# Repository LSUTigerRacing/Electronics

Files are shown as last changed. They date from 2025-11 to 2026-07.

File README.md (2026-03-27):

<div align="center">
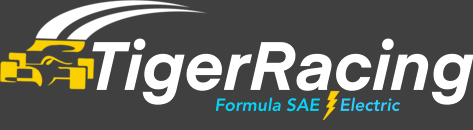
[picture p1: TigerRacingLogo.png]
TigerRacing Logo
    
</div>
<hr />
<div align="center">
    
</div>
<br />
<div align="center">
    This repository contains all of the KiCad Schematics for the TigerRacing Formula SAE's Electronics Subsystem.
</div>
<br />

## Prerequisites
* [Git](https://git-scm.com/downloads)
* [KiCad](https://www.kicad.org/download/)
* A [GitHub](https://github.com) account

## Board Templates
When making a new PCB, if the board is to be manufactured by **JLCPCB**. import the corresponding board constraints from `Board Templates/JLC` 

## Getting Started
This section will walk you through downloading the repository to your computer for the first time. You only need to do this once.

### 1. Generate a GitHub Token
A token is essentially a password that lets Git on your computer talk to GitHub securely.

1. Log into [GitHub](https://github.com)
2. Click your profile picture → **Settings**
3. Scroll down and click **Developer settings** (bottom of the left sidebar)
4. Click **Personal access tokens** → **Tokens (classic)**
5. Click **Generate new token (classic)**
6. Give it a name (e.g. `git-access`), set an expiration, and check the **repo** scope
7. Click **Generate token** and **copy it** — you won't be able to see it again!

### 2. Clone the Repository
"Cloning" means downloading a full copy of the repository to your computer.

Open **Git Bash** and run the following commands one at a time:
```sh
git clone https://github.com/LSUTigerRacing/Electronics.git
cd Electronics
```

When prompted for a password, paste the token you copied in the previous step.

### 3. Open the Project in KiCad
In **Git Bash**, highlight and right-click `Electronics` to open the folder in File Explorer. From there, open the KiCad project file (`.kicad_pro`).

---

## Contributing
This section covers the full workflow for making changes and submitting them every time you work on something.

> [!IMPORTANT]
> **Never commit directly to `main`.** All changes must go through a pull request.

### Step 1 — Make sure you're up to date
Before starting any work, pull the latest changes from the repository so you're not working on an outdated copy.
```sh
cd Electronics
git pull origin main
```

### Step 2 — Create a branch
A "branch" is your own isolated workspace. Think of it like making a photocopy of the project — you make your edits on the copy, and only merge it back once everything looks good.

Replace `your-branch-name` with something descriptive (e.g. `fault-latch-rework`).
```sh
git checkout -b "your-branch-name"
```

### Step 3 — Make your edits
Open the KiCad project and make your changes. Save your work when done.

### Step 4 — Stage and commit your changes
"Staging" tells Git which files to include, and "committing" saves a snapshot of those changes with a description.
```sh
git add .
git commit -m "Brief description of what you changed"
```

### Step 5 — Push your branch to GitHub
"Pushing" uploads your local branch so others (and GitHub) can see it.
```sh
git push -u origin "your-branch-name"
```

### Step 6 — Open a Pull Request
1. Go to the [repository on GitHub](https://github.com/LSUTigerRacing/Electronics)
2. Click the **Pull requests** tab
3. Click **New pull request**
4. Set the **base** branch to `main` and the **compare** branch to yours
5. Give it a clear title and description of what you changed
6. Click **Create pull request**

A reviewer will look over your changes. Once approved, your branch will be merged into `main` and can then be deleted.

---

## PCB Gallery

### Fault Latch
FaultLatch

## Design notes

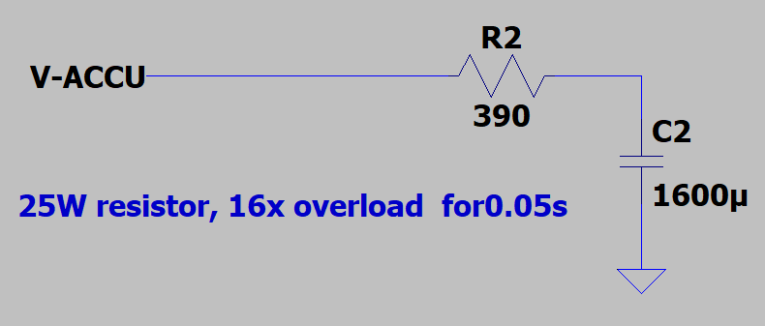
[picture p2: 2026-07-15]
PrechargeDischarge/Precharge26/docs/precharge-400V-390ohm-schematic.png

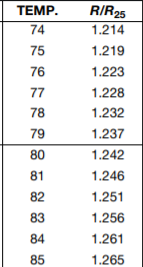
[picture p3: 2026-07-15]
PrechargeDischarge/Precharge26/docs/thermistor-response.png

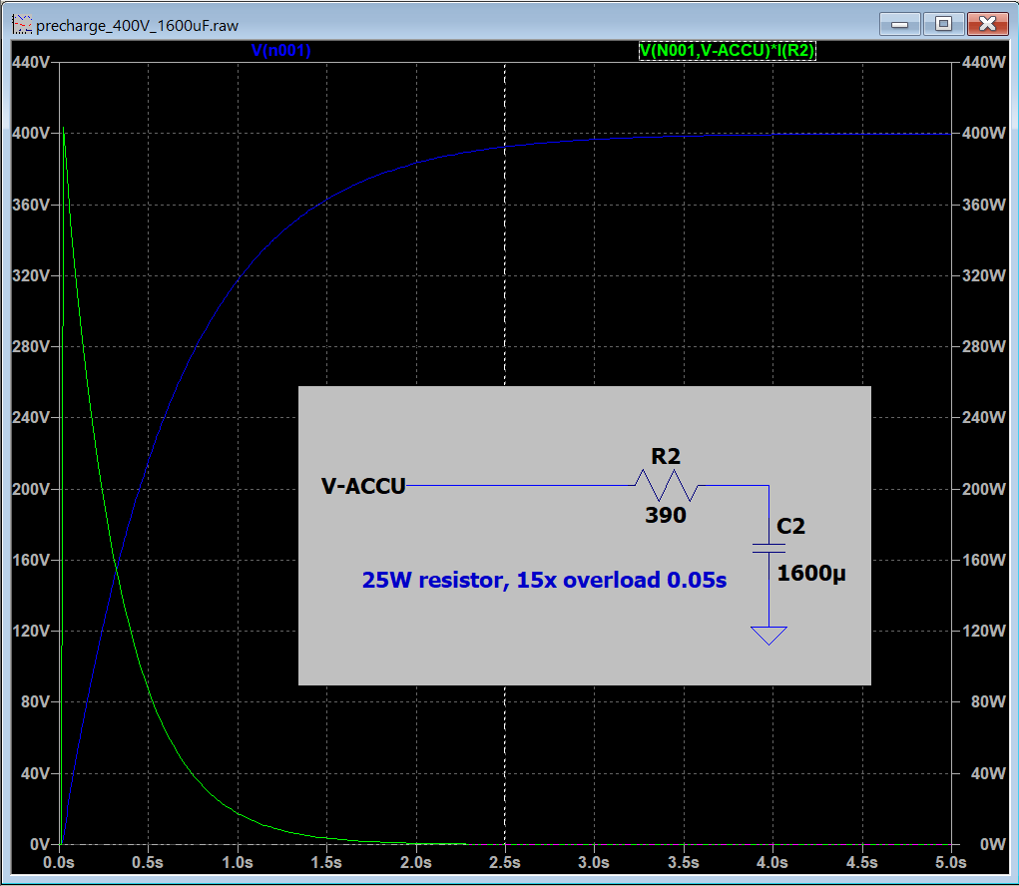
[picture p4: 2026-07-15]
PrechargeDischarge/Precharge26/docs/precharge-400V-390ohm-simulation.png

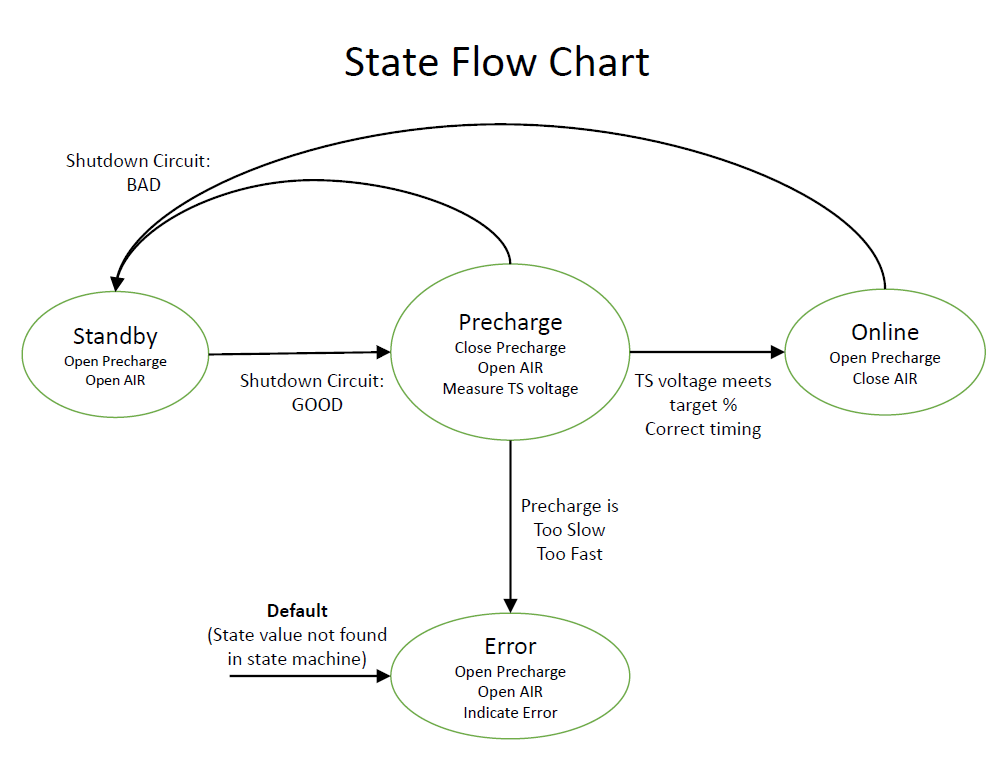
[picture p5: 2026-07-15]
PrechargeDischarge/Precharge26/docs/state-flow-chart.png

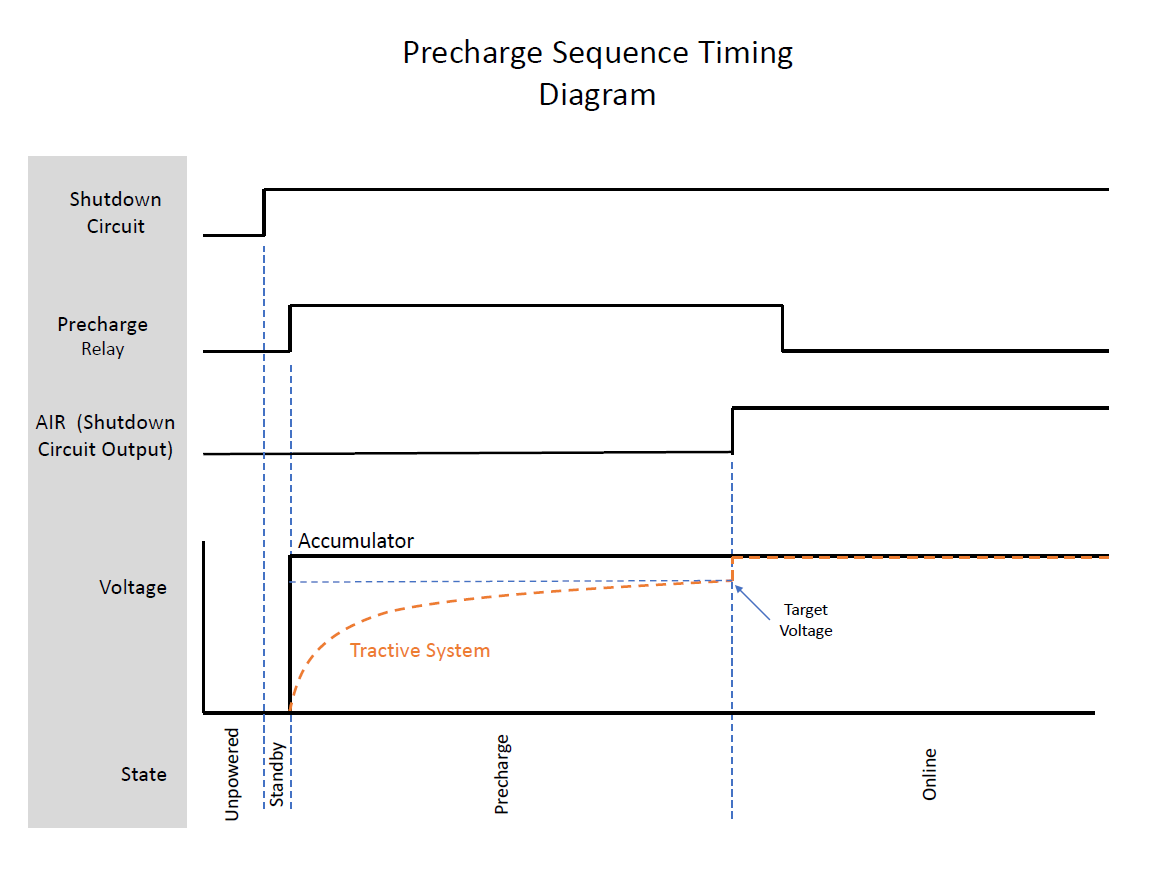
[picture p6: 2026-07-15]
PrechargeDischarge/Precharge26/docs/timing-diagram.png

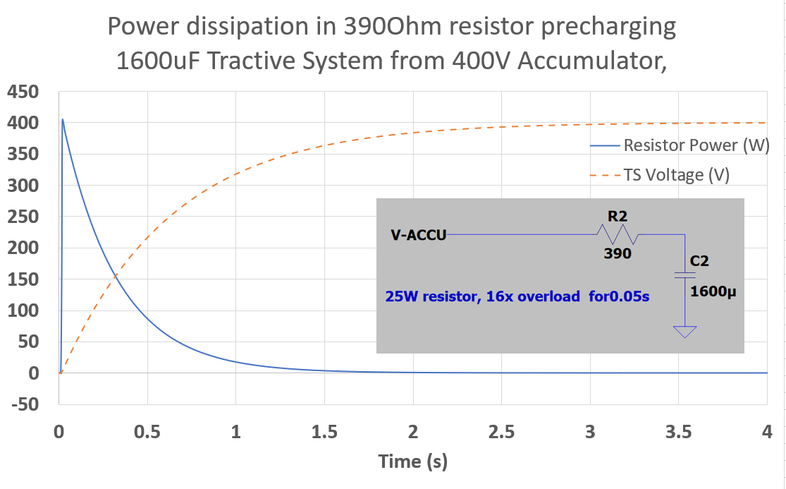
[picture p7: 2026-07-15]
PrechargeDischarge/Precharge26/docs/precharge-power.png

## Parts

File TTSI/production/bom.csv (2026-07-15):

Designator | Footprint | Quantity | Value | LCSC Part #
C101, C102 | 0402 | 2 | 10uF
C103, C105, C107 | 0402 | 3 | 0.1u
C104 | 0402 | 1 | 1u
C106 | 0402 | 1 | .01u
C108 | 0402 | 1 | 22u
D101, D102 | D_SOD-123F | 2 | D_TVS
D103 | 0603 | 1 | RED
Q101, Q102, Q103, Q105, Q106 | SOT-23 | 5 | Q_NMOS_GSD
Q104 | SOT-523 | 1 | Q_PMOS_GSD
R101, R103, R105 | 0603 | 3 | 10k
R102 | 0603 | 1 | 500R
R104, R106 | 0603 | 2 | 1k
R107 | 0603 | 1 | 15k
R108 | 0603 | 1 | 100k
U101, U102, U105 | 641964-1_TYC | 3 | 641964-1
U103 | R-78E-0.5_RCP | 1 | R-78E5.0-0.5
U104 | SOT-353_SC-70-5 | 1 | 74AHC1G32
U106 | SOT-353_SC-70-5 | 1 | 74AHC1G08
U107 | SOIC-8_3.9x4.9mm_P1.27mm | 1 | LM555xM

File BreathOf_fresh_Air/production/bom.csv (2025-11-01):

Designator | Footprint | Quantity | Value | LCSC Part #
C1 | CAP_1005_TDK | 1 | CGA2B3X7R1E224K050BB
C2 | CAP_CL21_SAM | 1 | CL21B224KAFNNNE
CR1 | CR_SOD323_MCC | 1 | 1N4148WX-TP
J2 | CONN_SD-43650-010_04_MOL | 1 | 436500428
J3 | CONN_SD-43650-010_02_MOL | 1 | 436500227
R1 | RES_CRCW_0402 | 1 | CRCW040210K0FKED
U1 | DCY4_TEX | 1 | LM7805MPX/NOPB
U2 | PAN_ALD_PAN | 1 | ALDP105W

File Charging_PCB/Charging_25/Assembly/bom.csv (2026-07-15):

Designator | Footprint | Quantity | Value | JLC #
C1, C117, C2 | 603 | 3 | 100n | C1591
C101, C102 | 603 | 2 | 10n | C1589
C105 | 402 | 1 | 0.33u | C107013
C106 | 402 | 1 | 0.01u | C15195
D1, D2 | 805 | 2 | LED | C19171391
D101, D102 | D_SMA | 2 | D_Schottky | C8678
K101, K102 | Relay_SPDT_Omron_G2RL-1 | 2 | Relay_SPDT_Omron_G2RL-1 | C469130
Q1, Q2 | TO-252-2 | 2 | NMOS | C2889156
Q101, Q102, Q107, Q108 | SOT-523_Custom(C96676) | 4 | Q_PMOS_GSD | C96676
Q103, Q104, Q105, Q106 | SOT-23 | 4 | Q_NPN_BEC | C2146
R1, R105, R106, R2, R5, R6 | 805 | 6 | 10k | C17590
R101, R108, R109, R111, R113 | 805 | 5 | 1K | C17513
R102 | 805 | 1 | 2.2K | C17520
R103, R104, R110, R112 | 805 | 4 | 100k | C149504
R3, R4 | 805 | 2 | 270 | C17590
SW101, SW102 | SW_SPST_Omron_B3FS-100xP | 2 | SW_Omron_B3FS | C271750
U107 | TO-220-3_Vertical | 1 | LM7805_TO220 | C71107
U3, U4 | SOT-23-5 | 2 | 74AHC1G00 | C350556

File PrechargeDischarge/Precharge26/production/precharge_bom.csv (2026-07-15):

Designator | Footprint | Quantity | Value | LCSC Part #
C1, C11, C12, C15, C16, C17, C18, C19, C2, C20, C21, C22, C23 | 0805 | 13 | 100n
C10, C3, C8, C9 | 0805 | 4 | 1u
C13, C14 | 0805 | 2 | 10n
C4, C5, C6, C7 | C_Elec_6.3x5.4 | 4 | 220u
D1, D12, D7, D8, D9 | D_SMA | 5 | D
D10, D11 | SOT-23 | 2 | BZX84C12
D2, D3, D4, D5 | 0805 | 4 | LED
D6 | SOT-23 | 1 | BZX84C3V3
J1 | Molex_Micro-Fit_3.0_43045-0812_2x04_P3.00mm_Vertical | 1 | MicroFit
J2 | MICROFIT-4PIN | 1 | Mini-Fit_Jr_5566-04A
J3 | MICROFIT-4PIN | 1 | 447690401
JP1, JP2, JP3 | SolderJumper-2_P1.3mm_Open_RoundedPad1.0x1.5mm | 3 | SolderJumper_2_Open
K1 | OMRON-G2R-24 | 1 | OMRON-G2RL-24 | C1524522
K2 | G7L-2A-X-L | 1 | G7L-2A-X-L
Q1, Q3 | SOT-23 | 2 | 2N7002
Q2 | SOT-23 | 1 | MMBT3906
R1 | 1206 | 1 | 160
R10, R23, R24, R7 | 1206 | 4 | 6k8
R11, R12 | 1206 | 2 | 1k5
R13, R17, R26 | 1206 | 3 | 12k
R14, R16 | 1206 | 2 | 47
R15, R18 | 1206 | 2 | 560
R19, R47 | 1206 | 2 | 220
R2, R3, R4, R5 | 1206 | 4 | 200
R20, R22, R25, R28 | 1206 | 4 | 100k
R21, R27, R29, R44, R45, R48, R8 | 1206 | 7 | 10k
R30 | 1206 | 1 | 500k
R31, R32, R33, R34, R36, R37, R38, R40, R41, R42 | 1206 | 10 | 510k
R35 | 1206 | 1 | 2k2
R39, R43 | 1206 | 2 | 39k
R46 | Chassis_Resistor_TE_Connectivity_HSA25 | 1 | HSA253K3J
R49 | 1206 | 1 | 0
R6, R9 | 1206 | 2 | 20k
TH1 | 1206 | 1 | TFPT1206L1002FM
TP1, TP2, TP3, TP4, TP5, TP6 | TestPoint_Loop_D2.50mm_Drill1.0mm_LowProfile | 6 | TestPoint
U1 | SOIC-8_3.9x4.9mm_P1.27mm | 1 | TJA1051T-3
U10 | SOIC-8_3.9x4.9mm_P1.27mm | 1 | LM393
U11, U5, U6 | SMDIP-6_W7.62mm | 3 | 4N35
U2 | DC-DCSPAN02W8-12 | 1 | SPAN02A-12
U3 | Teensy40 | 1 | Teensy4.0
U4 | SOT-223-3_TabPin2 | 1 | LM1117-5.0
U7, U8 | DIP-8_W7.62mm | 2 | LM331
U9 | SOIC-8_3.9x4.9mm_P1.27mm | 1 | LM2904

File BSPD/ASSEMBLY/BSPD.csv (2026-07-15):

Value | Reference | Footprint | JLCPCB Part #
0.1uF | C101,C103,C106,C107,C109 | Capacitor_SMD:C_0402_1005Metric | C1525
10uF | C102,C104,C108 | Capacitor_SMD:C_0805_2012Metric | C1713
0.01uF | C105 | Capacitor_SMD:C_0402_1005Metric | C1524
Q_NMOS_GSD | Q1,Q2 | Package_TO_SOT_SMD:SOT-23 | C151421
10k | R1 | Resistor_SMD:R_0805_2012Metric | C17590
10K | R101,R102,R103 | Resistor_SMD:R_1206_3216Metric | C1489
10K | RV101,RV102,RV103,RV104 | 3224W-1-103E:POT_3224W | C81348
R-78E5.0-0.5 | U103 | R_78E5_0_0_5:R-78E-0.5_RCP | C18212367
SN74LVC1G08DBVR | U104,U109 | SN74LVC1G08DBVR:DBV0005A_L | C7666
LM339DR | U105 | LM339DR:D14 | C7948
NE555DR | U106 | NE555DR:D8 | C7593
SN74LVC3G14DCUR | U107 | SN74LVC3G14DCUR:DCU8_TEX | C98856
SN74AC32DR | U108 | D14 | C352943

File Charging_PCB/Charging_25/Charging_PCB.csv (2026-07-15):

Value | Reference | Footprint | JLC#
D_Schottky | D101,D102 | Diode_SMD:D_SMA | C8678
Relay_SPDT_Omron_G2RL-1 | K101,K102 | Relay_THT:Relay_SPDT_Omron_G2RL-1 | C1524507
Q_PMOS_GSD | Q101,Q102 | Library:SOT-523_Custom(C96676) | C96676
1K | R101 | Resistor_SMD:R_0805_2012Metric_Pad1.20x1.40mm_HandSolder | C17513
2.2K | R102 | Resistor_SMD:R_0805_2012Metric_Pad1.20x1.40mm_HandSolder | C17520

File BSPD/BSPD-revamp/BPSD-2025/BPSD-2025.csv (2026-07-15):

Reference | Qty | Value | DNP | Exclude from BOM | Exclude from Board | Footprint | Datasheet
C1,C2 | 2 | 10uF |  |  |  |  | ~
C3,C4,C10 | 3 | 100uF |  |  |  |  | ~
C5,C6,C7,C8,C9 | 5 | 0.1uF |  |  |  |  | ~
J1 | 1 | Conn(BSE_1) |  |  |  |  | ~
J2 | 1 | Conn(BSE_2) |  |  |  |  | ~
J5 | 1 | Conn(12V) |  |  |  |  | ~
J6 | 1 | Conn(Hall Effect) |  |  |  |  | ~
Q1,Q2 | 2 | NMOS |  |  |  |  | https://ngspice.sourceforge.io/docs/ngspice-html-manual/manual.xhtml#cha_MOSFETs
R1,R5,R14,R15,R16,R17 | 6 | 100k |  |  |  |  | ~
R2 | 1 | 41 |  |  |  |  | ~
R3 | 1 | 1k |  |  |  |  | ~
R4,R19,RV2,RV4,RV5 | 5 | 10k |  |  |  |  | ~
R6,R7,R8,R11,R12,R13 | 6 | 100k |  |  |  | Resistor_SMD:R_0603_1608Metric | ~
R9,R18 | 2 | 2.2k |  |  |  | Resistor_SMD:R_0603_1608Metric | ~
R10 | 1 | 15k |  |  |  | Resistor_SMD:R_0603_1608Metric | ~
R20 | 1 | 1k |  |  |  | Resistor_SMD:R_0603_1608Metric | ~
TP4 | 1 | TP_BSE_1 |  |  |  |  | ~
TP5 | 1 | TB_BSE_2 |  |  |  |  | ~
TP6 | 1 | TP_ACCUM_V |  |  |  |  | ~
TP7 | 1 | TP_CHARGE |  |  |  |  | ~
TP8 | 1 | TP_ACCUM |  |  |  |  | ~
TP9 | 1 | TP_BSE |  |  |  |  | ~
TP10 | 1 | TP_GND |  |  |  |  | ~
U1,U6,U9,U13,U14,U15 | 6 | LM393P |  |  |  | Package_DIP:DIP-8_W7.62mm_LongPads | https://www.ti.com/lit/ds/symlink/lm393.pdf?ts=1759105947618
U2,U5 | 2 | LM339 |  |  |  |  | https://www.st.com/resource/en/datasheet/lm139.pdf
U3 | 1 | 74AUC2G32 |  |  |  |  | http://www.ti.com/lit/sg/scyt129e/scyt129e.pdf
U4 | 1 | 74AUC2G08 |  |  |  |  | http://www.ti.com/lit/sg/scyt129e/scyt129e.pdf
U7,U11 | 2 | SN74AHC1G08DBVR |  |  |  | Package_TO_SOT_SMD:SOT-23-5 | https://www.ti.com/lit/ds/symlink/sn74ahc1g08.pdf?HQS=dis-dk-null-digikeymode-dsf-pf-null-wwe&ts=1759156244542
U8 | 1 | SN74AHC1G00DBVR |  |  |  | Package_TO_SOT_SMD:SOT-23-5 | https://www.ti.com/lit/ds/symlink/sn74ahc1g00.pdf?HQS=dis-dk-null-digikeymode-dsf-pf-null-wwe&ts=1759114924595
U17,U18 | 2 | SN74AHC1G32DBVR |  |  |  | Package_TO_SOT_SMD:SOT-23-5 | https://www.ti.com/lit/ds/symlink/sn74ahc1g32.pdf?HQS=dis-dk-null-digikeymode-dsf-pf-null-wwe&ts=1759100923895
U104 | 1 | R-78E5.0-0.5 |  |  |  | R_78E5_0_0_5:R-78E-0.5_RCP | R-78E5.0-0.5

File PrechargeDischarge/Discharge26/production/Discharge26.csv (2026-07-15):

Reference | Qty | Value | DNP | Exclude from BOM | Exclude from Board | Footprint | Datasheet | MFR | JLC
D1 | 1 | Schottky |  |  |  | Diode_SMD:D_SMA | https://jlcpcb.com/api/file/downloadByFileSystemAccessId/8586172667489079296 | SS34 | C8678
J1 | 1 | HV_Conn |  |  |  | Discharge:MicroFit_4pin | ~
J2 | 1 | LV_Conn |  |  |  | Connector_Molex:Molex_Nano-Fit_105313-xx03_1x03_P2.50mm_Horizontal | https://jlcpcb.com/partdetail/MOLEX-1053131103/C561764 | 1053131103 | C561764
Q5 | 1 | NMOS |  |  |  | Package_TO_SOT_SMD:SOT-23
R50 | 1 | HSA503K0J |  |  |  | Discharge:Discharge_Resistor | https://www.digikey.com/en/products/detail/te-connectivity-passive-product/HSA503K0J/5587244
R51 | 1 | 10k |  |  |  | Resistor_SMD:R_1206_3216Metric | ~

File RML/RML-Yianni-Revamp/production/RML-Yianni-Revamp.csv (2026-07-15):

Reference | Qty | Value | DNP | Exclude from BOM | Exclude from Board | Footprint | Datasheet | JLC | JLC# | MOUSER | Digikey Link
C1,C3,C4,C6,C7 | 5 | 10u |  |  |  | Capacitor_SMD:C_0603_1608Metric | ~ |  | C70225
C2,C8,C9,C10 | 4 | 1u |  |  |  | Capacitor_SMD:C_0603_1608Metric | ~ |  | C1592
C5,C11,C12 | 3 | 100n |  |  |  | Capacitor_SMD:C_0603_1608Metric | ~ |  | C1590
D1 | 1 | 12V |  |  |  | Diode_SMD:D_SOD-123 | https://jlcpcb.com/api/file/downloadByFileSystemAccessId/8586176365943001088 |  | C43491
J1 | 1 | MICROFIT-4PIN |  |  |  | RML:MICROFIT-4PIN | https://www.molex.com/en-us/products/part-detail-pdf/447640401?display=pdf
J2 | 1 | SAMMY-6PIN |  |  |  | BSPD:SAMMY-6PIN | https://www.molex.com/en-us/products/part-detail-pdf/1053141106?display=pdf
PS1 | 1 | IA1212D |  |  |  | Converter_DCDC:Converter_DCDC_XP_POWER-IAxxxxD_THT | https://www.digikey.com/en/products/detail/xp-power/IA1212D/4487740?s=N4IgTCBcDaIJIEECMYUBEQF0C%2BQ |  |  |  | https://www.digikey.com/en/products/detail/xp-power/IA1212D/4487740?s=N4IgTCBcDaIJIEECMYUBEQF0C%2BQ
Q1,Q2 | 2 | NMOS |  |  |  | Package_TO_SOT_SMD:SOT-23 | https://jlcpcb.com/api/file/downloadByFileSystemAccessId/8579710867975426048 |  | C2590
R1,R2,R3,R4 | 4 | 249k |  |  |  | Resistor_SMD:R_1206_3216Metric | https://jlcpcb.com/partdetail/35547-1206W4F2493T5E/C34578 | C34578
R5 | 1 | 49k9 |  |  |  | Resistor_SMD:R_1206_3216Metric | https://jlcpcb.com/partdetail/18705-1206W4F4992T5E/C18017 |  | C18017
R6 | 1 | 2k2 |  |  |  | Resistor_SMD:R_1206_3216Metric | https://jlcpcb.com/parts/2nd/Resistors/Chip_Resistor_Surface_Mount_2980 |  | C17948
R7,R8 | 2 | 100 |  |  |  | Resistor_SMD:R_1206_3216Metric | https://jlcpcb.com/partdetail/18589-1206W4F1000T5E/C17901 |  | C17901
R9 | 1 | 75k |  |  |  | Resistor_SMD:R_1206_3216Metric | https://jlcpcb.com/partdetail/18674-1206W4F7502T5E/C17986 |  | C17986
R10 | 1 | 24k |  |  |  | Resistor_SMD:R_1206_3216Metric | https://jlcpcb.com/partdetail/18648-1206W4F2402T5E/C17960 |  | C17960
R11 | 1 | 910 |  |  |  | Resistor_SMD:R_1206_3216Metric | https://jlcpcb.com/partdetail/YAGEO-RC1206FR07910RL/C137224 |  | C137224
R12 | 1 | 1k |  |  |  | Resistor_SMD:R_1206_3216Metric | ~ |  | C1469
R13 | 1 | 1M |  |  |  | Resistor_SMD:R_1206_3216Metric | https://jlcpcb.com/partdetail/18615-1206W4F1004T5E/C17927 |  | C17927
R14 | 1 | 47k |  |  |  | Resistor_SMD:R_1206_3216Metric | ~ |  | C25664
R15,R17 | 2 | 100k |  |  |  | Resistor_SMD:R_1206_3216Metric | https://jlcpcb.com/parts/2nd/Resistors/Chip_Resistor_Surface_Mount_2980 |  | C17900
R16 | 1 | 10k |  |  |  | Resistor_SMD:R_1206_3216Metric | https://jlcpcb.com/parts/2nd/Resistors/Chip_Resistor_Surface_Mount_2980 |  | C1489
U1 | 1 | LM397 |  |  |  | Package_TO_SOT_SMD:SOT-23-5 | http://www.ti.com/lit/ds/symlink/lm397.pdf |  | C132076
U2 | 1 | SFH617A-1 |  |  |  | Package_DIP:DIP-4_W7.62mm | https://www.mouser.com/ProductDetail/Vishay-Semiconductors/SFH617A-1?qs=xCMk%252BIHWTZPd%252B0%2F2oZ4QGA%3D%3D |  |  | SFH617A-1
U3 | 1 | LM1117DT-5.0 |  |  |  | Package_TO_SOT_SMD:TO-252-3_TabPin2 | http://www.ti.com/lit/ds/symlink/lm1117.pdf |  | C354068
U4 | 1 | 74AHC1G02 |  |  |  | Package_TO_SOT_SMD:SOT-23-5 | https://www.ti.com/cn/lit/ds/symlink/sn74ahc1g02.pdf?ts=1743093850620 |  | C7463
U5 | 1 | LM555xM |  |  |  | Package_SO:SOIC-8_3.9x4.9mm_P1.27mm | http://www.ti.com/lit/ds/symlink/lm555.pdf |  | C90760

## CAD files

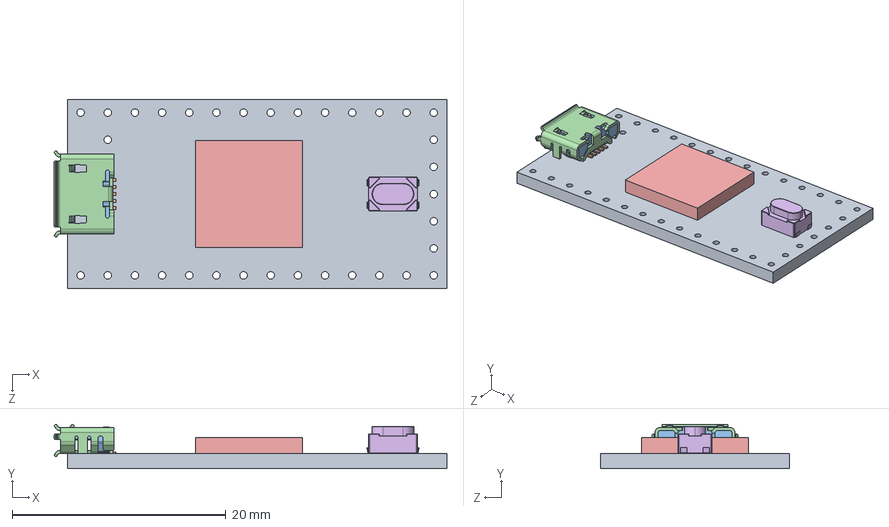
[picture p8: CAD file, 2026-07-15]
PrechargeDischarge/Precharge26/CAD-files/Teensy_4.0_Assembly.STEP
36.8 x 4.12 x 17.7 mm
Teensy_4.0_PCB
Micro USB-B Female 5Pin SMD
NXP iMXRT1062
SKRPACE010 v4

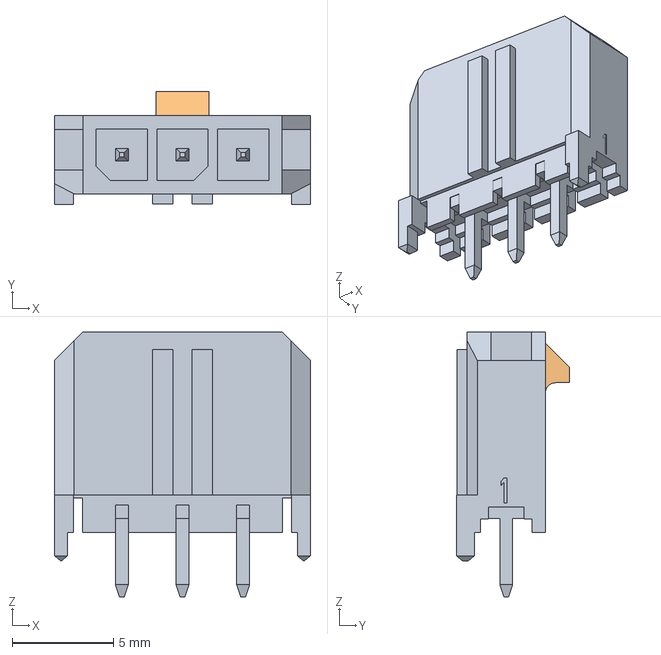
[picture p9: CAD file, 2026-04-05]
B.TR.27/IRresistable/3D Models/MicroFit 3-Pos.stp
12.7 x 5.61 x 13.1 mm

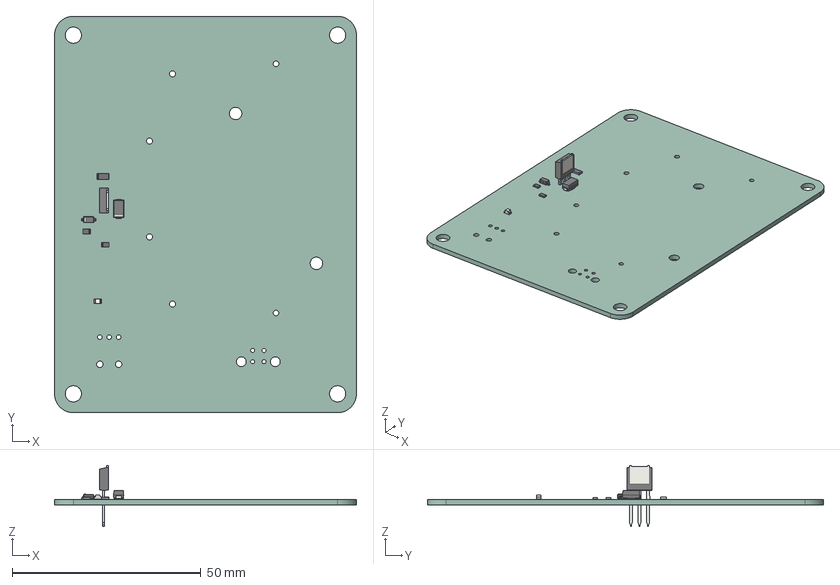
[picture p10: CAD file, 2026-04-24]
B.TR.27/PCBModal26/BoardStepfiles/Discharge26.step
80.0 x 105.0 x 16.3 mm
D_SOD-123
R_0805_2012Metric x 2
LED_0805_2012Metric
D_SMA
TO-251-3_Vertical
R_1206_3216Metric
Discharge26_PCB

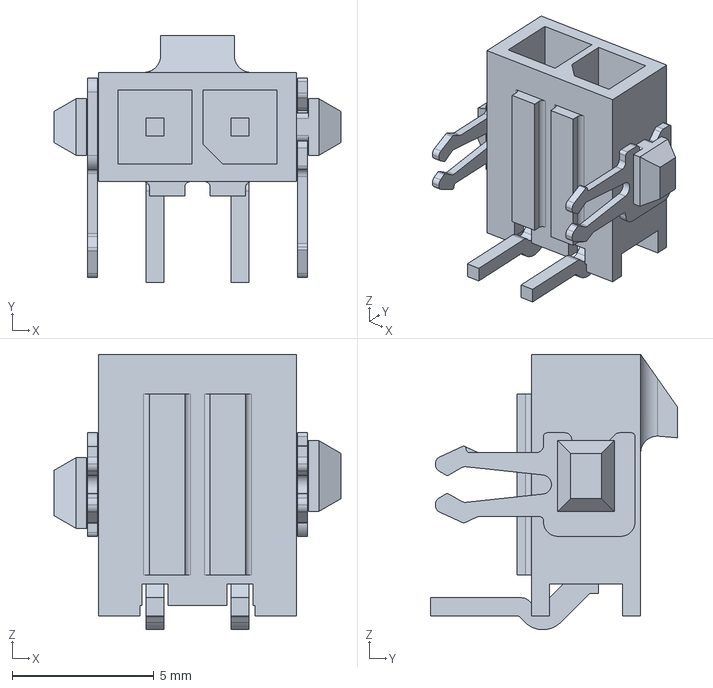
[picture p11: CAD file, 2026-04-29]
B.TR.27/RML/RML Quick/2_1445054_2/c-2-1445054-2-b-3d.stp
10.1 x 8.72 x 9.73 mm

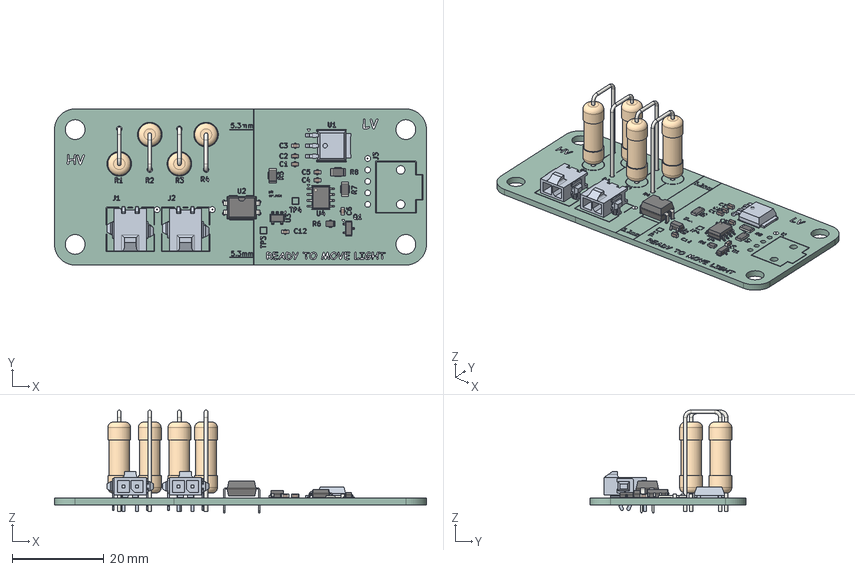
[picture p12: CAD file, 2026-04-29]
B.TR.27/RML/RML Quick/RML Quick.step
81.0 x 34.0 x 22.4 mm
SOT-23-5
R_Axial_DIN0516_L15.5mm_D5.0mm_P7.62mm_Vertical x 4
C_0603_1608Metric x 7
DIP-4_W7.62mm
R_1206_3216Metric x 3
SOIC-8_3.9x4.9mm_P1.27mm
SOT-23
c-2-1445054-2-b-3d x 2
R_0805_2012Metric
RML Quick 1.21.1
RML Quick_silkscreen
RML Quick_PCB

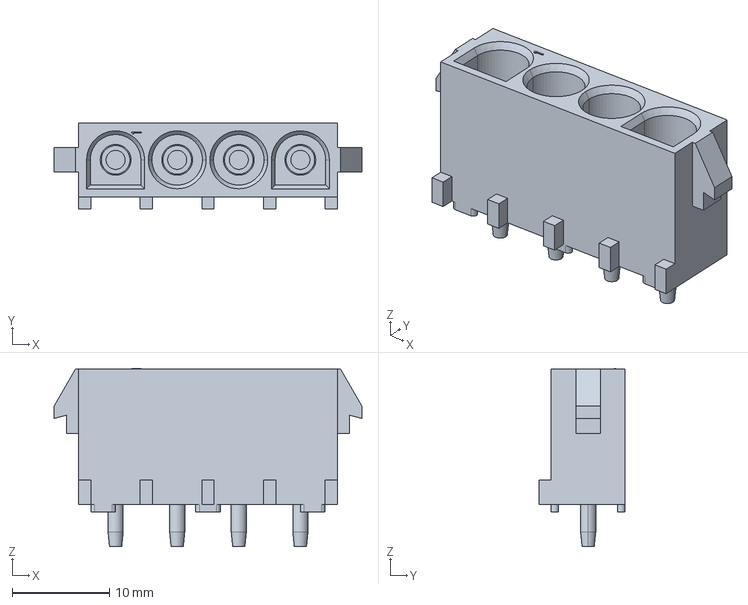
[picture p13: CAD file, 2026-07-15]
BSPD/350826-1/c-0350826-01-p-3d.stp
31.8 x 8.89 x 18.4 mm

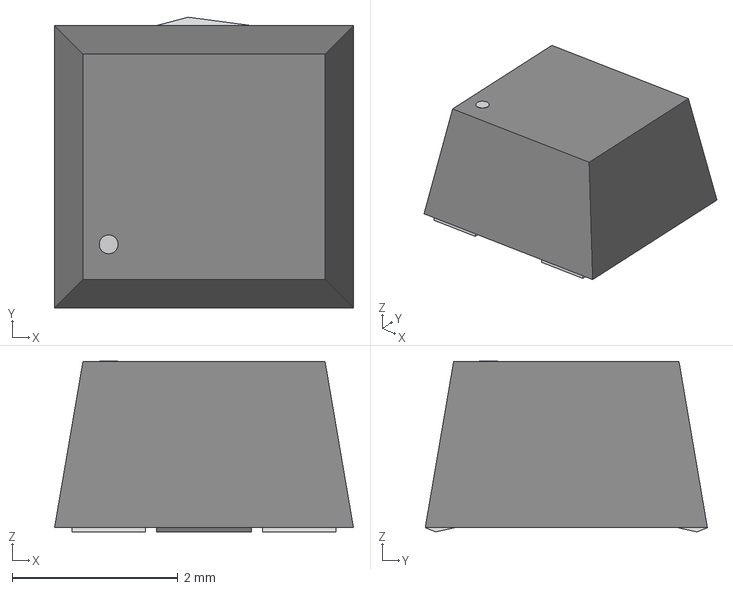
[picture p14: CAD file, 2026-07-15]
BSPD/PVG3A103C01R00/RES_C01R00.step
3.61 x 3.50 x 2.06 mm

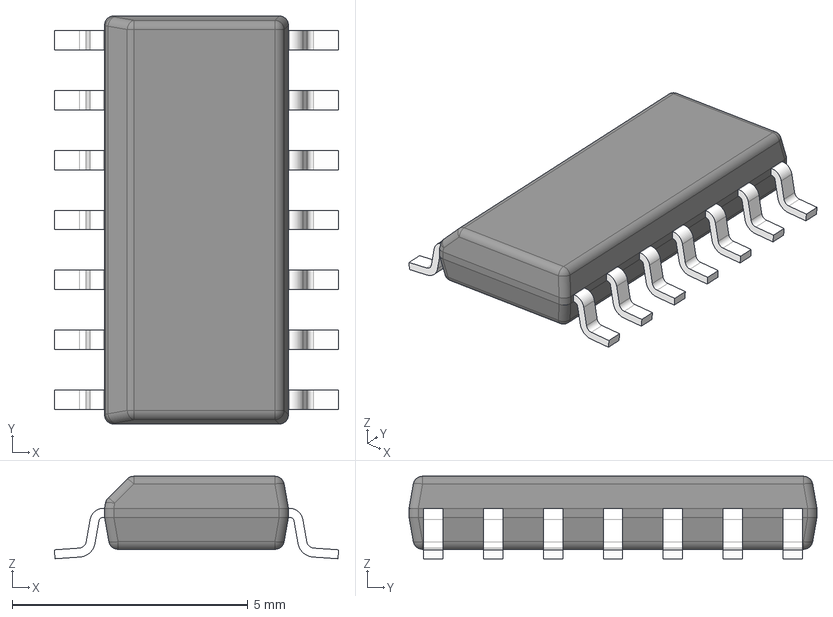
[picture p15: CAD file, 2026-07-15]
BSPD/SN74HC32DR (4)/D0014A.stp
6.03 x 8.65 x 1.75 mm
BODY-SO
LEAD-SO x 14
PIN1-ID

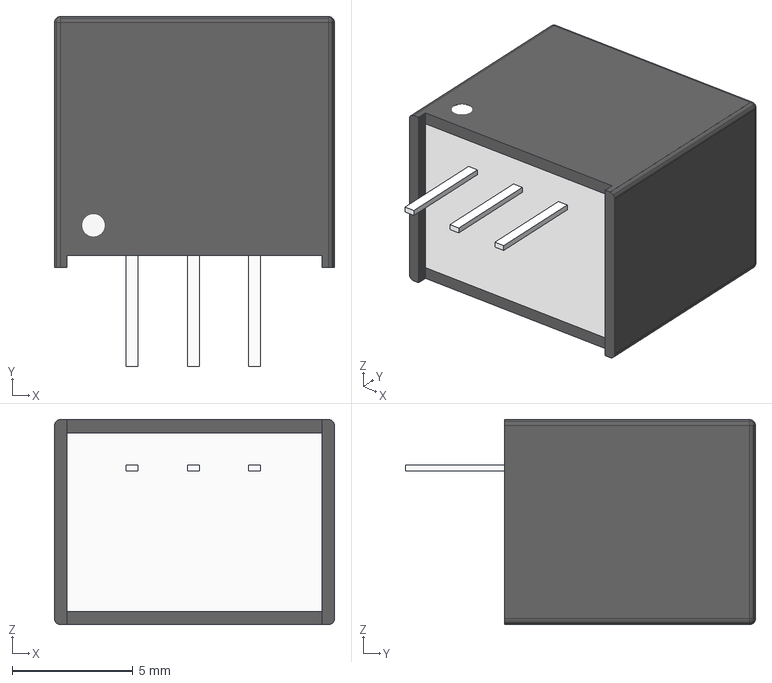
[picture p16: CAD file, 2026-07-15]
BSPD/StepFile-173.stp
11.6 x 14.5 x 8.51 mm

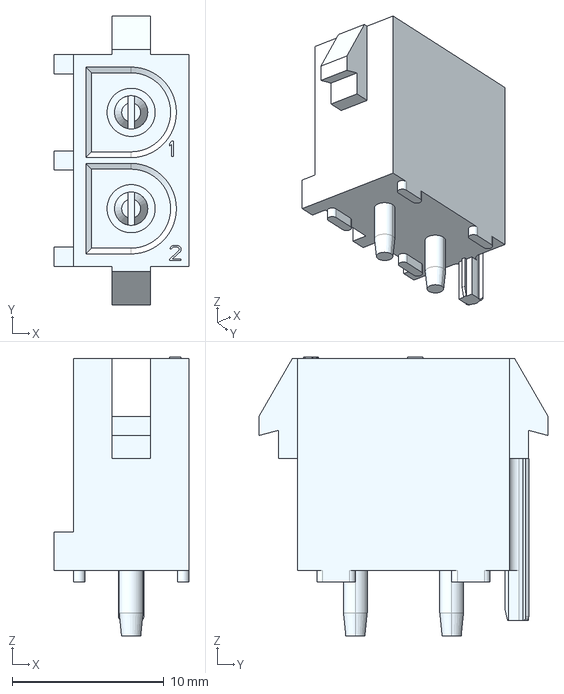
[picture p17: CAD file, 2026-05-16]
Charging_PCB/Charging_25/Downloads/CONN/c-641964-1-p-3d.stp
8.89 x 19.1 x 18.4 mm

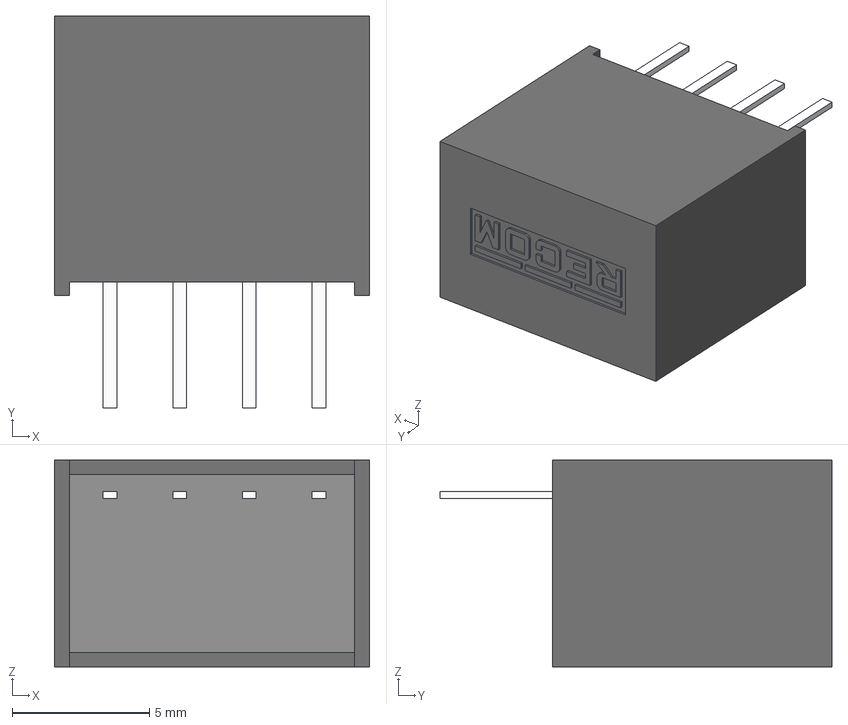
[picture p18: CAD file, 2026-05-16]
Charging_PCB/Charging_25/Downloads/ISOLATED_CONVERTER/KiCad/RI-1205S.stp
11.5 x 14.3 x 7.55 mm

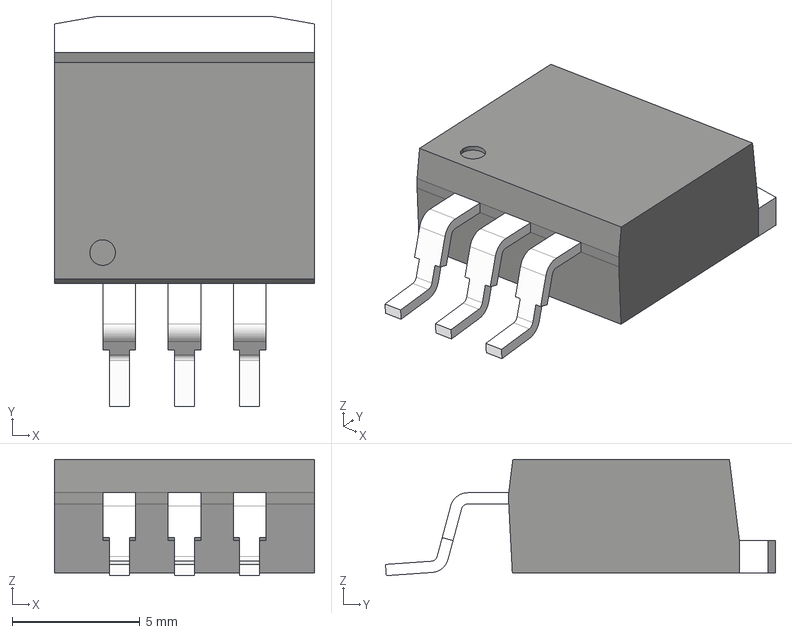
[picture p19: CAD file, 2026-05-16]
Charging_PCB/Charging_25/Downloads/REGULATOR/LM7805SX_NOPB.stp
10.2 x 15.2 x 4.54 mm
BODY-TO
HTSINK-TO263
LEAD-TO263 x 3

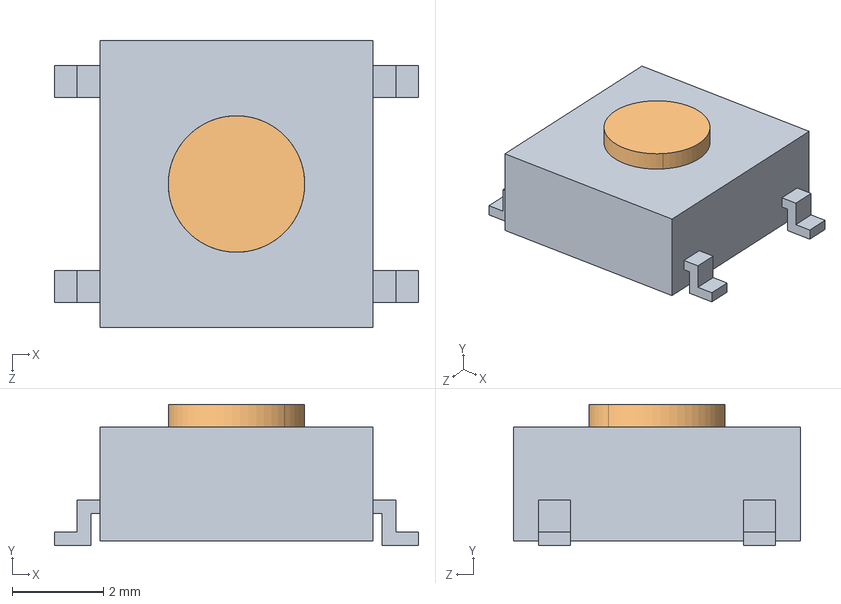
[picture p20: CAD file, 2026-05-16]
Charging_PCB/Charging_25/Downloads/SWITCH_3D/B3FS_1000.step
8.00 x 3.10 x 6.30 mm
B3FS_1000_BASE
B3FS_1000_BUTTON

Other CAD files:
B.TR.27/BSPD-2026-relayout/180375945-659-1053131102/1053131102.stp
B.TR.27/IRresistable/3D Models/MicroFit 2-Pos.stp
B.TR.27/PCBModal26/BoardStepfiles/BPSD-2025.step
B.TR.27/PCBModal26/BoardStepfiles/ChargingPCB26.step
B.TR.27/PCBModal26/BoardStepfiles/IRresistable.step
B.TR.27/PCBModal26/BoardStepfiles/RML-Yianni-Revamp.step
B.TR.27/Safety circuit PCB/Old_SafetyCircuit/Imports/0430450801.stp
B.TR.27/Safety circuit PCB/Old_SafetyCircuit/Imports/1053131202.stp
B.TR.27/Safety circuit PCB/Old_SafetyCircuit/Imports/1053141312.stp
B.TR.27/Safety circuit PCB/Old_SafetyCircuit/Imports/DT13-12PA-B016.stp
B.TR.27/Safety circuit PCB/Old_SafetyCircuit/TEST.step
BSPD-2026-relayout/173748557-659-1053131104/1053131104.stp
BSPD-2026-relayout/180375945-659-1053131102/1053131102.stp
BSPD/BSPD-revamp/BSPD-2025-relayout/173748557-659-1053131104/1053131104.stp
BSPD/D0008A.stp
BSPD/DBV0005A.stp
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

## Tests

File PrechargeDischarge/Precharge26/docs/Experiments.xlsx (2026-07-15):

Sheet: Precharge SPICE simulation
time | Resistor Power (W) | TS Voltage (V) | I(R2)
0 | 0 | 0 | 0
0.01 | 0 | 0 | 0
0.01001933312 | 0.001533361 | 1.324067e-05 | -0.00198285
0.01003875694 | 0.006162031 | 5.410287e-05 | -0.003974931
0.01006465535 | 0.01714794 | 0.0001560603 | -0.006630918
0.01011645219 | 0.05562289 | 0.0005211794 | -0.01194248
0.01022004587 | 0.1985613 | 0.001896134 | -0.02256395
0.01042723322 | 0.7482008 | 0.00722411 | -0.04380027
0.01084160793 | 2.900998 | 0.02818591 | -0.08624649
0.01167035734 | 11.40844 | 0.1112816 | -0.1710334
0.01332785617 | 45.13331 | 0.4417524 | -0.3401859
0.01664285383 | 178.882 | 1.585441 | -0.6772531
0.02 | 403.7442 | 3.187406 | -1.017468
0.03257764739 | 387.8121 | 11.09549 | -0.9971911
0.04515529479 | 372.4933 | 18.85388 | -0.9772978
0.05773294218 | 357.7698 | 26.46256 | -0.9577883
0.07031058957 | 343.6242 | 33.92155 | -0.9386627
0.08288823697 | 330.0393 | 41.23083 | -0.9199209
0.09546588436 | 316.9982 | 48.39041 | -0.901563
0.1080435318 | 304.4845 | 55.40029 | -0.883589
0.1317600496 | 282.2687 | 68.20969 | -0.8507444
0.1554765675 | 261.609 | 80.58257 | -0.8190191
0.1791930853 | 242.4221 | 92.51892 | -0.788413
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

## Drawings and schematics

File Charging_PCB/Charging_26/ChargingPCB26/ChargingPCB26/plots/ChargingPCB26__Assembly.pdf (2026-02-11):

1 | 2 | 3 | 4 | 5 | 6

A

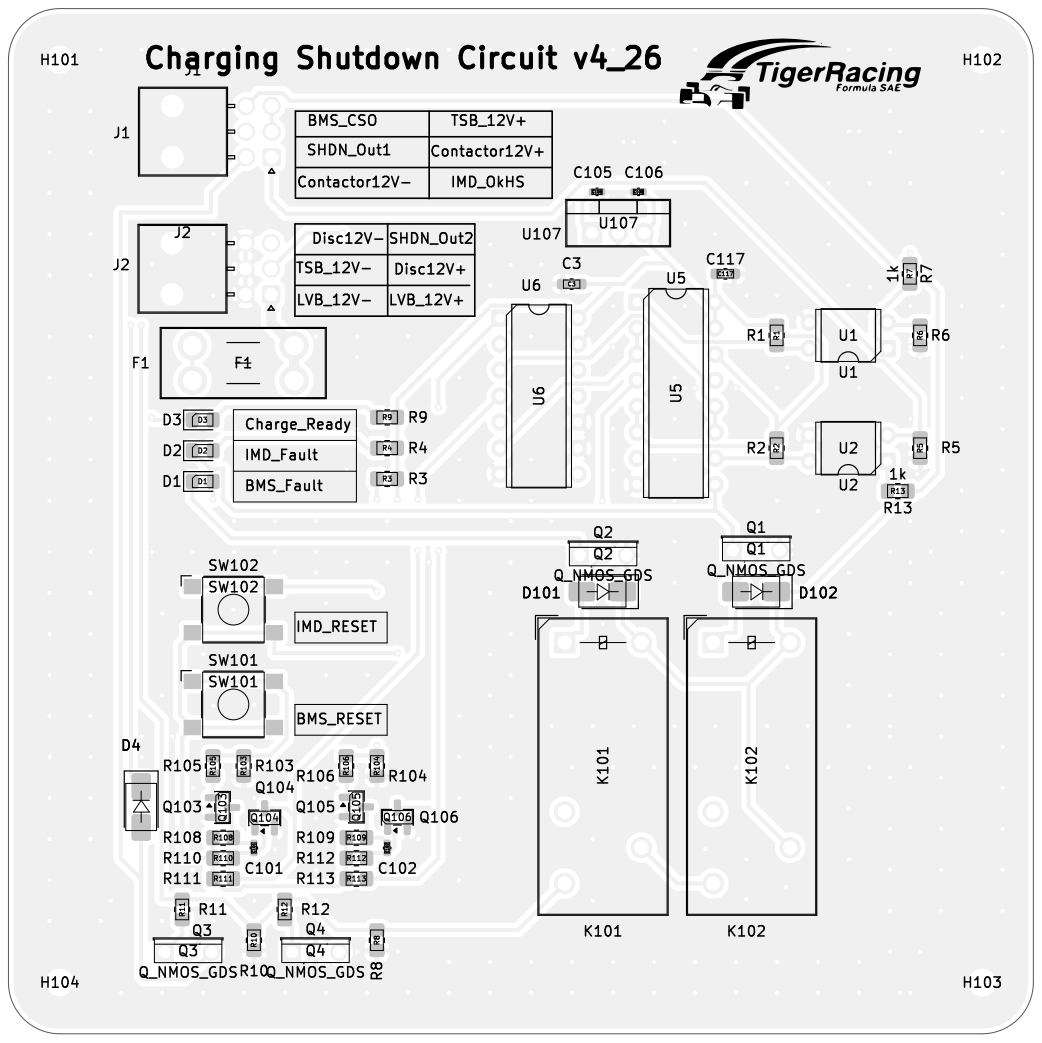
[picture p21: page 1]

Id: /1 Title: File: ChargingPCB26.kicad_pcb Sheet: Black And White TOP

1 | 2 | 3 | 4 | 5 | 6

A

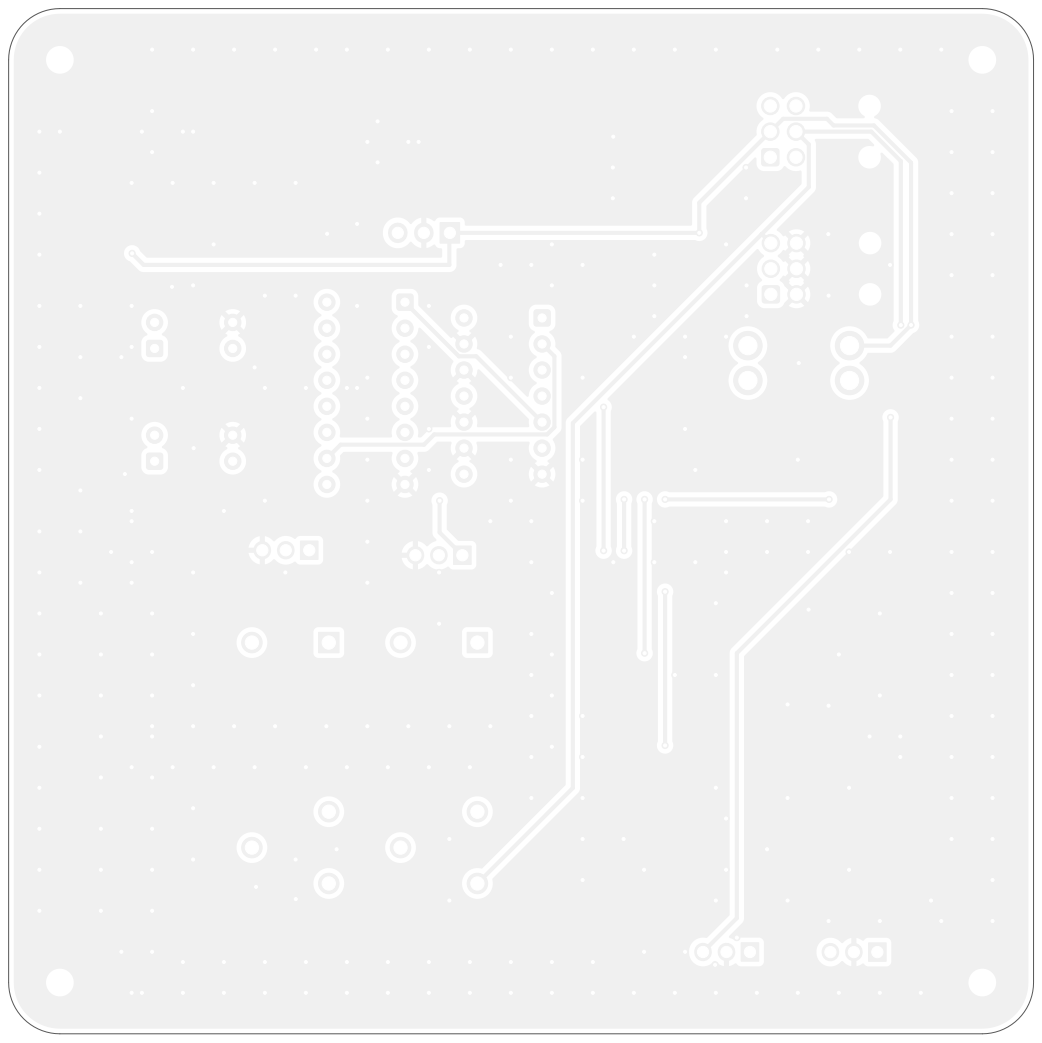
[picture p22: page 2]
D Date: KiCad; E.D.A. 9.0.7 Size: A4; Rev:; Id: /1 Title: File: ChargingPCB26.kicad_pcb Sheet: Black; And; White; BOT Board2Pdf:; Black; BOT -; Page 2/2

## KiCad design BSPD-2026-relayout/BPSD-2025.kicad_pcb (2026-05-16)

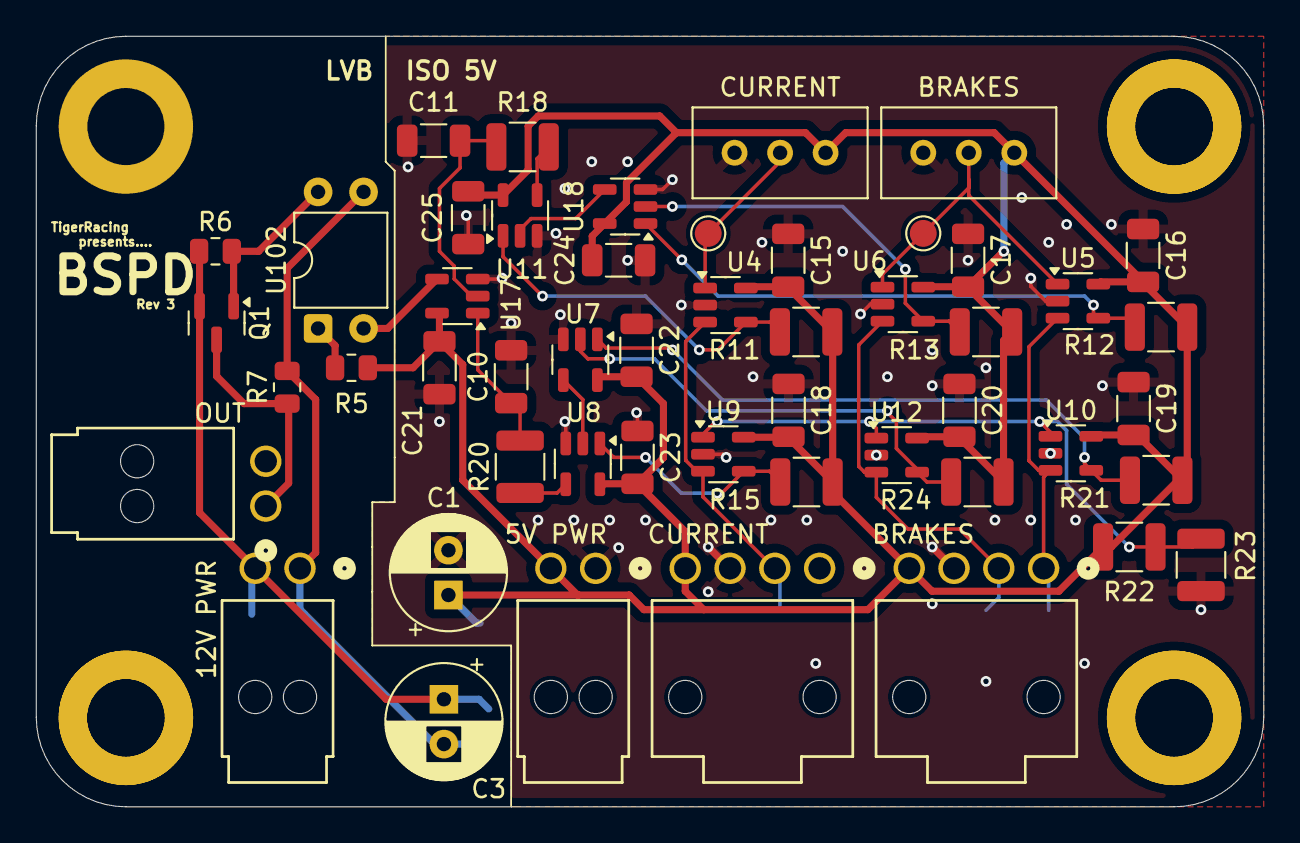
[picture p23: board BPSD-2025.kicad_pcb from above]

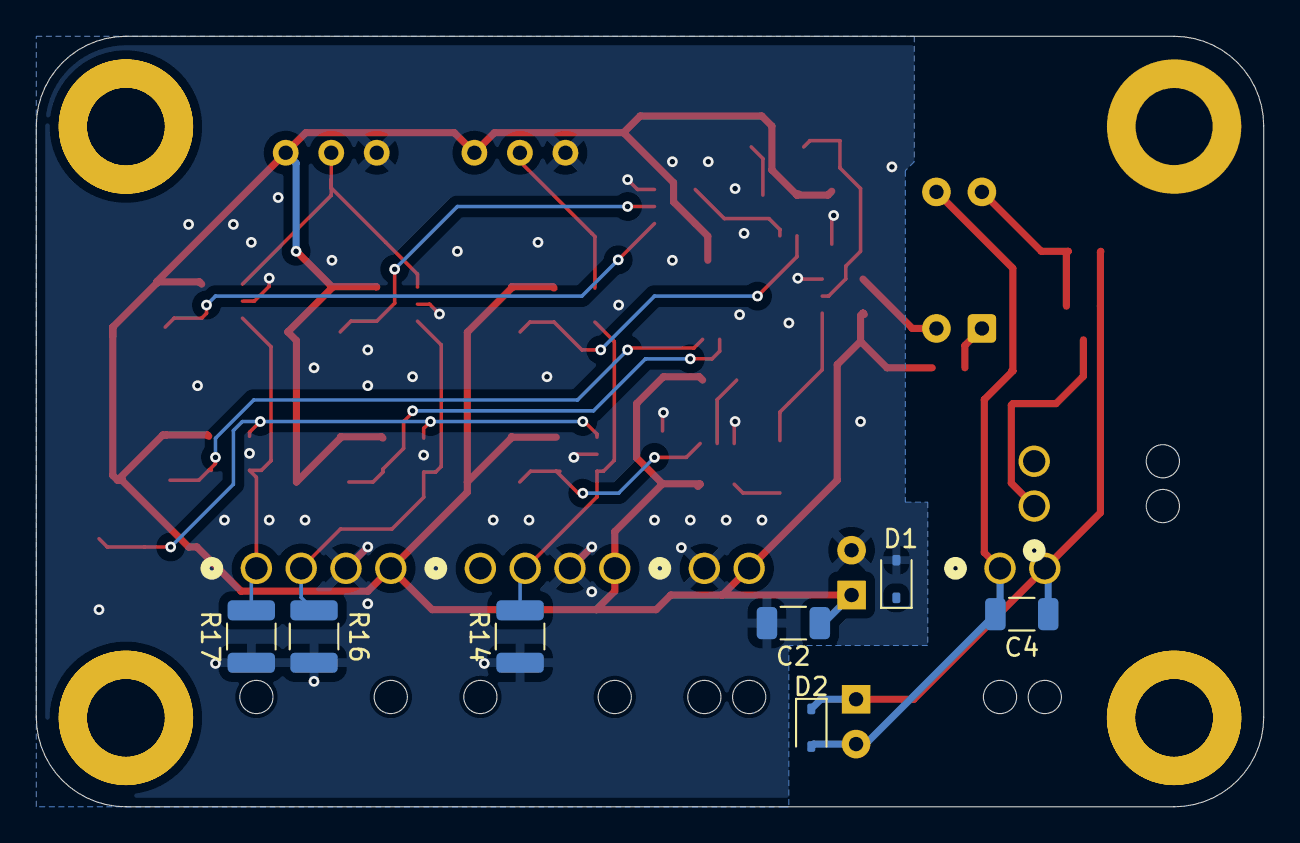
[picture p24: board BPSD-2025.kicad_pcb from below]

Board: 2 copper layers, 68.5 x 43.0 mm, 57 parts (7 on the bottom side), 26 nets.

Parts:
5V PWR, 12V PWR: SAMMY-2PIN
BRAKES: 10k; Potentiometer_Bourns_3296W_Vertical
BRAKES#2: SAMMY-4PIN
C1, C3: 100u; CP_Radial_D6.3mm_P2.50mm
C2, C4: 10u; C_1206_3216Metric
C10, C11: 100uF; C_1206_3216Metric
C15, C16, C17, C18, C19, C20, C21, C22, C23, C24, C25: 0.1uF; C_1206_3216Metric
CURRENT: 10k; Potentiometer_Bourns_3296W_Vertical
CURRENT#2: SAMMY-4PIN
D1: SD05.TCT; D_SOD-323
D2: SD12C.TCT; D_SOD-323
OUT: SAMMY-2PIN
Q1: Q_PMOS_GSD; SOT-23
R5: 1k; R_0805_2012Metric
R6, R7: 10k; R_0805_2012Metric
R11, R12, R13, R14, R15, R16, R17, R21, R24: 100k; R_1210_3225Metric
R18: 4k87; R_1210_3225Metric
R20, R23: 1k; R_1210_3225Metric
R22: 12k; R_1210_3225Metric
TP8: TP_ACCUM; TestPoint_Pad_D1.5mm
TP9: TP_BSE; TestPoint_Pad_D1.5mm
U4, U5, U6, U9, U10, U12: LM397; SOT-23-5
U7, U11: SN74AHC1G08DBVR; SOT-23-5
U8: SN74AHC1G00DBVR; SOT-23-5
U17, U18: SN74AHC1G32DBVR; SOT-23-5
U102: SFH617A-1; DIP-4_W7.62mm

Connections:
+5V: 5V PWR.2, BRAKES.1, BRAKES#2.4, C1.1, C2.1, C15.2, C16.2, C17.2, C18.2, C19.2, C20.2, C21.2, C22.2, C23.2, C24.2, C25.2, CURRENT.1, CURRENT#2.4, D1.1 (K), R5.1, R11.2, R12.2, R13.2, R15.2, R21.2, R22.2, R24.2, U4.5 (V+), U5.5 (V+), U6.5 (V+), U7.5 (VCC), U8.5 (VCC), U9.5 (V+), U10.5 (V+), U11.5 (VCC), U12.5 (V+), U17.5 (VCC), U18.5 (VCC)
/0.385V: R22.1, R23.2, U9.1 (-), U10.1 (-), U12.1 (-)
/ACCUM_V: CURRENT#2.2, R14.2, U4.3 (+), U9.3 (+)
/BAT+: 12V PWR.2, C3.1, C4.1, D2.1 (K), Q1.2 (S), R6.1
/BRAKE+CURRENT_HOLD: R18.1, U11.4
/BSE_1: BRAKES#2.1, R17.2, U5.3 (+), U10.3 (+)
/BSE_2: BRAKES#2.2, R16.2, U6.3 (+), U12.3 (+)
/DISCONNECT_HOLD: R20.1, U8.4
/THRESH_ACCUM: CURRENT.2, TP8.1, U4.1 (-)
/THRESH_BSE: BRAKES.2, TP9.1, U5.1 (-), U6.1 (-)
BSPD_OUT: OUT.1, Q1.3 (D), R7.1
GND: 5V PWR.1, BRAKES.3, BRAKES#2.3, C1.2, C2.2, C10.2, C11.2, C15.1, C16.1, C17.1, C18.1, C19.1, C20.1, C21.1, C22.1, C23.1, C24.1, C25.1, CURRENT.3, CURRENT#2.3, D1.2 (A), R14.1, R16.1, R17.1, R23.1, U4.2 (V-), U5.2 (V-), U6.2 (V-), U7.3 (GND), U8.3 (GND), U9.2 (V-), U10.2 (V-), U11.3 (GND), U12.2 (V-), U17.3 (GND), U18.3 (GND)
GNDPWR: 12V PWR.1, C3.2, C4.2, D2.2 (A), R7.2, U102.3
unnamed: C10.1, R20.2, U17.1
unnamed: C11.1, R18.2, U17.2
unnamed: Q1.1 (G), R6.2, U102.4
unnamed: R5.2, U102.1
unnamed: R11.1, U4.4, U11.1
unnamed: R12.1, U5.4, U18.1
unnamed: R13.1, U6.4, U18.2
unnamed: R15.1, U8.1, U9.4
unnamed: R21.1, U7.1, U10.4
unnamed: R24.1, U7.2, U12.4
unnamed: U7.4, U8.2
unnamed: U11.2, U18.4
unnamed: U17.4, U102.2

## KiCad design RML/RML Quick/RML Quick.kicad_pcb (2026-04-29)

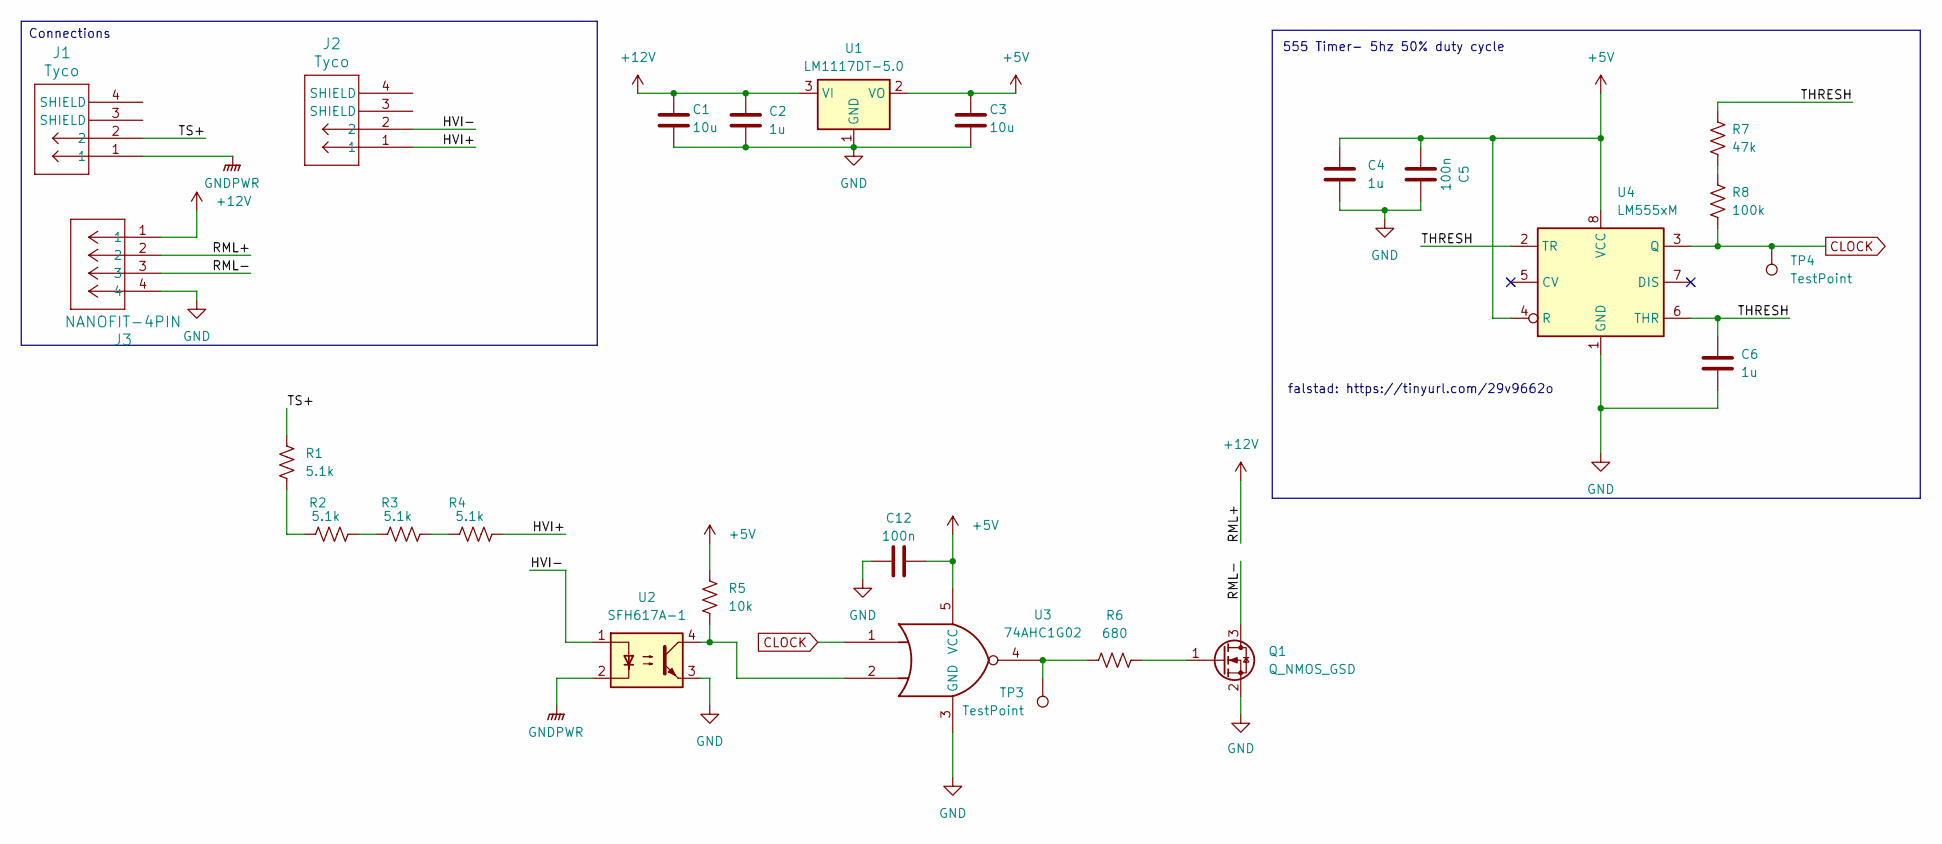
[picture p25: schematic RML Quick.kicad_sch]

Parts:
C1, C3: 10u; C_0603_1608Metric; JLC# C70225
C2, C4, C6: 1u; C_0603_1608Metric; JLC# C1592
C5, C12: 100n; C_0603_1608Metric; JLC# C1590
J1, J2: Tyco; tyco
J3: NANOFIT-4PIN; SAMMY-4PIN
Q1: Q_NMOS_GSD; SOT-23; JLC# C2590
R1, R2, R3, R4: 5.1k; R_Axial_DIN0516_L15.5mm_D5.0mm_P7.62mm_Vertical; MFR# RR03J5K1TB
R5: 10k; R_1206_3216Metric; JLC# C1489
R6: 680; R_0805_2012Metric; MFR# CR0805-JW-681ELF
R7: 47k; R_1206_3216Metric; JLC# C25664
R8: 100k; R_1206_3216Metric; JLC# C17900
TP3, TP4: TestPoint; TestPoint_Pad_1.0x1.0mm
U1: LM1117DT-5.0; TO-252-3_TabPin2; JLC# C354068
U2: SFH617A-1; DIP-4_W7.62mm; MOUSER SFH617A-1
U3: 74AHC1G02; SOT-23-5; Mouser 595-SN74AHC1G02DBE4
U4: LM555xM; SOIC-8_3.9x4.9mm_P1.27mm; JLC# C90760

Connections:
+5V: C3.1, C4.1, C5.1, C12.2, R5.1, U1.2 (VO), U3.5 (VCC), U4.4 (R), U4.8 (VCC)
+12V: C1.1, C2.1, J3.1, J3.2, U1.3 (VI)
/HVI+: J2.1, R4.2
/HVI-: J2.2, U2.1
/RML-: J3.3, Q1.3 (D)
/THRESH: C6.1, R7.1, U4.2 (TR), U4.6 (THR)
/TS+: J1.2, R1.1
CLOCK: R8.2, TP4.1, U3.1, U4.3 (Q)
GND: C1.2, C2.2, C3.2, C4.2, C5.2, C6.2, C12.1, J3.4, Q1.2 (S), U1.1 (GND), U2.3, U3.3 (GND), U4.1 (GND)
GNDPWR: J1.1, U2.2
unnamed: Q1.1 (G), R6.2
unnamed: R1.2, R2.1
unnamed: R2.2, R3.1
unnamed: R3.2, R4.1
unnamed: R5.2, U2.4, U3.2
unnamed: R6.1, TP3.1, U3.4
unnamed: R7.2, R8.1

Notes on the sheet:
555 Timer- 5hz 50% duty cycle
falstad: https://tinyurl.com/29v9662o
Connections

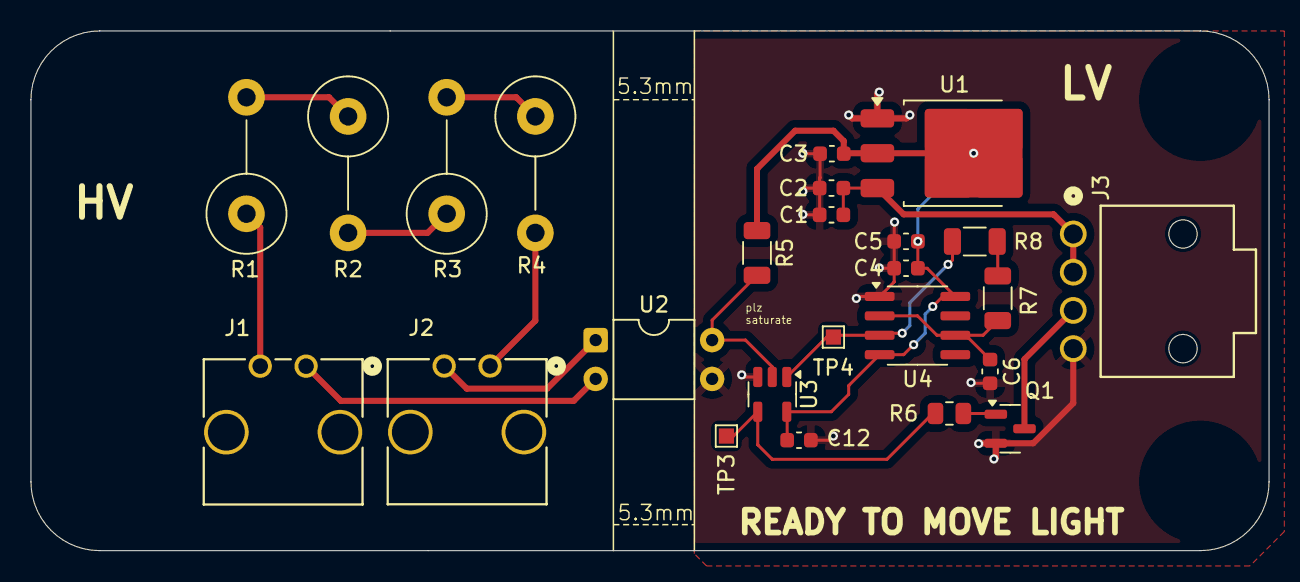
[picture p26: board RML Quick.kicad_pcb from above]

Board: 2 copper layers, 81.0 x 34.0 mm, 25 parts (0 on the bottom side), 17 nets.

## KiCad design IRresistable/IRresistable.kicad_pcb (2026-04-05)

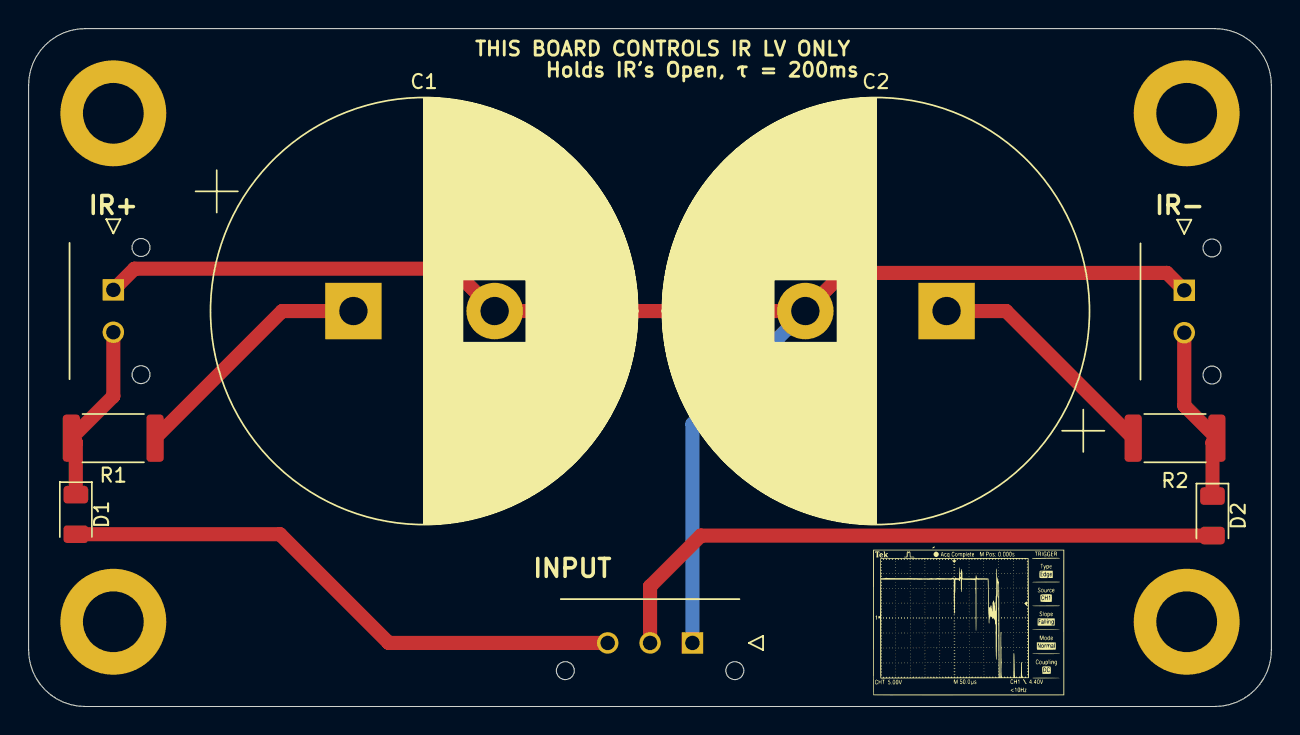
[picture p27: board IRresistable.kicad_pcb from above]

Board: 2 copper layers, 88.0 x 48.0 mm, 13 parts (0 on the bottom side), 7 nets.

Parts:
C1, C2: 4.7m; CP_Radial_D30.0mm_P10.00mm_SnapIn
D1, D2: SD1206T020S1R0; D_1206_3216Metric
H1, H2, H3, H4: MountingHole; MountingHole_4.3mm_M4_DIN965_Pad
INPUT: MicroFit 3-Pos
IR+: MicroFit 2-Pos
IR-: MicroFit 2-Pos
R1, R2: 10; R_2512_6332Metric

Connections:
/IR+ HOLD: D1.1 (K), IR+.2, R1.2
/IR+ INPUT: D1.2 (A), INPUT.3
/IR- HOLD: D2.1 (K), IR-.2, R2.2
/IR- INPUT: D2.2 (A), INPUT.2
GNDPWR: C1.2, C2.2, INPUT.1, IR+.1, IR-.1
unnamed: C1.1, R1.1
unnamed: C2.1, R2.1

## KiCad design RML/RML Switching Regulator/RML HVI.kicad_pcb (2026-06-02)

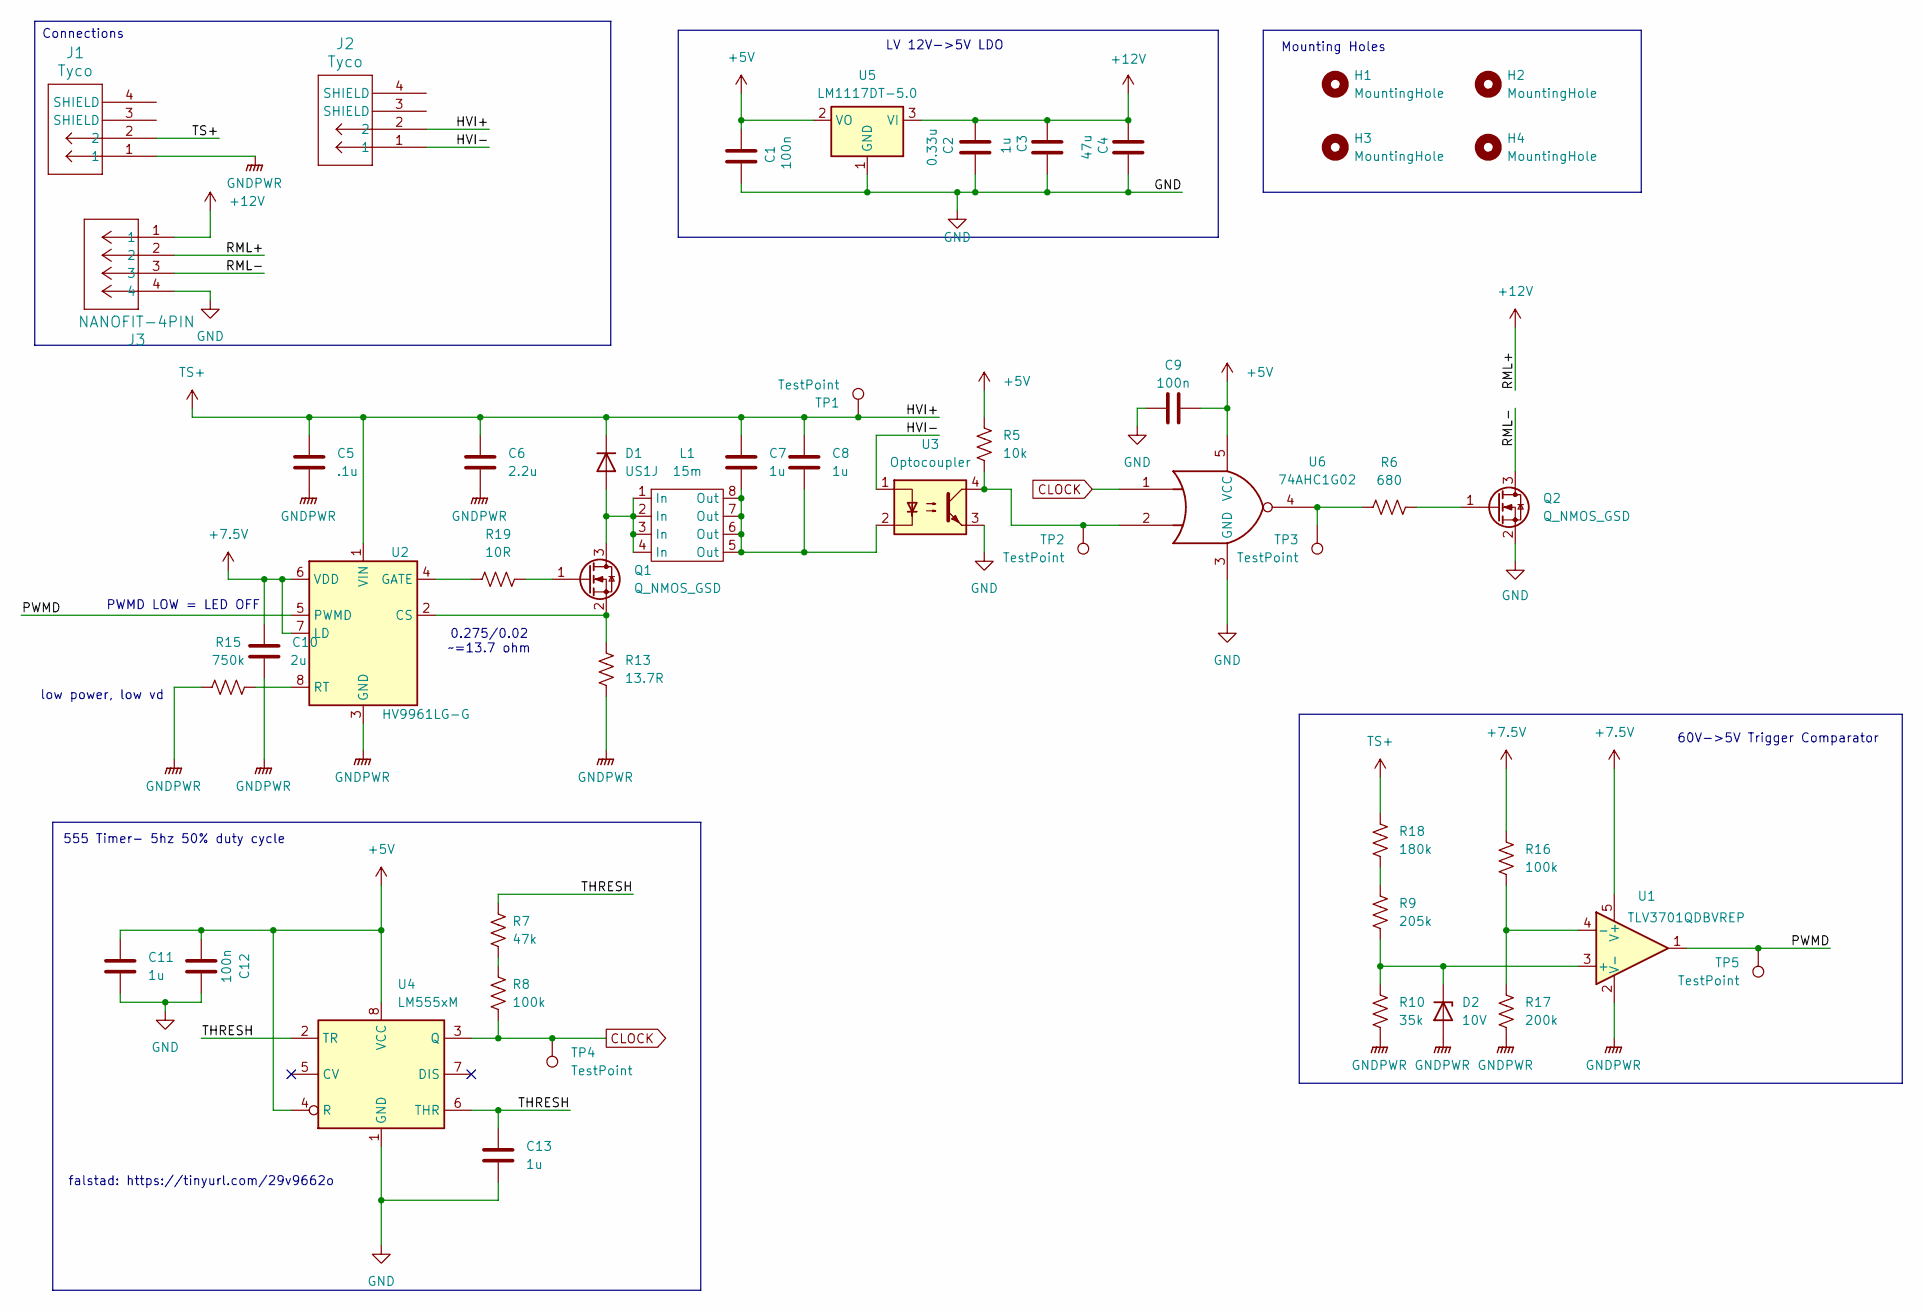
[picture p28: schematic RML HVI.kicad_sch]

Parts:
C1: 100n; C_0603_1608Metric_Pad1.08x0.95mm_HandSolder; JLC# C1591
C2: 0.33u; C_0603_1608Metric_Pad1.08x0.95mm_HandSolder; JLC# C282682
C3: 1u; C_0805_2012Metric_Pad1.18x1.45mm_HandSolder; JLC# C91186
C4: 47u; CP_Elec_6.3x5.4; JLC# C2836440
C5: .1u; C_1210_3225Metric; Manufacture# C1210X104JCRAC3316; Mouser# 80-C1210X104JCR3316
C6: 2.2u; CAPC6050X550N; Manufacture# CKG57NX7T2W225M500JH; Mouser# 810-CKG57NX7T2W225M
C7, C8: 1u; C_1210_3225Metric; Manufacture# KAF32GR71H105KU; Mouser# 581-KAF32GR71H105KU
C9, C12: 100n; C_0603_1608Metric; JLC# C1590
C10: 2u; C_0805_2012Metric; Manufacture# GXT21BR71C225KE01L; Mouser# 81-GXT21BR71C225KE1L
C11, C13: 1u; C_0603_1608Metric; JLC# C1592
D1: US1J; D_SMA; Mouser 637-US1J
D2: 10V; Nexperia_CFP3_SOD-123W; Manufacture# MMSZ5240C-HE3_A-08; Mouser# 78-MMSZ5240CHE3_A-08
H1, H2, H3, H4: MountingHole; MountingHole_3.2mm_M3_DIN965_Pad_TopOnly
J1, J2: Tyco; tyco
J3: NANOFIT-4PIN; Molex_Nano-Fit_105313-xx04_1x04_P2.50mm_Horizontal
L1: 15m; IND_BOURNS_SRR0908; Manufacture# SRR0908-153YL; Mouser# 652-SRR0908-153YL
Q1: Q_NMOS_GSD; TO-252-3_TabPin2; Manufacture# IPD70R1K4P7SAUMA1; Mouser# 726-IPD70R1K4P7AUMA1
Q2: Q_NMOS_GSD; SOT-23; JLC# C2590
R5: 10k; R_0805_2012Metric
R6: 680; R_0805_2012Metric; MFR# CR0805-JW-681ELF
R7: 47k; R_1206_3216Metric; JLC# C25664
R8: 100k; R_1206_3216Metric; JLC# C17900
R9: 205k; R_1210_3225Metric; Manufacture# AC1210FR-07205KL; Mouser# 603-AC1210FR-07205KL
R10: 35k; R_0402_1005Metric; Manufacture# RC0402FR-0735KL; Mouser# 603-RC0402FR-0735KL
R13: 13.7R; R_0805_2012Metric; Manufacture# RC0805FR-0713R7L; Mouser# 603-RC0805FR-0713R7L
R15: 750k; R_0805_2012Metric
R16: 100k; R_0805_2012Metric; Manufacture# RE0805FRE1010KL; Mouser# 603-RE0805FRE1010KL
R17: 200k; R_0805_2012Metric; Manufacture# AC0805FR-0720KL; Mouser# 603-AC0805FR-0720KL
R18: 180k; R_1210_3225Metric; Manufacture# RC1210FR-07180KL; Mouser# 603-RC1210FR-07180KL
R19: 10R; R_0201_0603Metric; Manufacture# 0603WAF100JT1E; Mouser# 303-0603WAF100JT1E
TP1, TP2, TP3, TP4, TP5: TestPoint; TestPoint_Pad_1.0x1.0mm
U1: TLV3701QDBVREP; SOT-23-5; Manufacture# TLV3701QDBVREP; Mouser# 595-TLV3701QDBVREP
U2: HV9961LG-G; SOIC-8_3.9x4.9mm_P1.27mm
U3: Optocoupler; Q_Wurth_WL-OCPT_LSOP4-STANDARD; Manufacture# VOLA617A-3X001T; Mouser# 78-VOLA617A-3X001T
U4: LM555xM; SOIC-8_3.9x4.9mm_P1.27mm; JLC# C90760
U5: LM1117DT-5.0; TO-252-3_TabPin2; JLC# C354068
U6: 74AHC1G02; SOT-23-5; Mouser 595-SN74AHC1G02DBE4

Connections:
+5V: C1.2, C9.2, C11.1, C12.1, R5.1, U4.4 (R), U4.8 (VCC), U5.2 (VO), U6.5 (VCC)
+7.5V: C10.1, R16.1, U1.5 (V+), U2.6 (VDD), U2.7 (LD)
+12V: C2.1, C3.1, C4.1, J3.1, J3.2, U5.3 (VI)
/HVI-: J2.1, U3.1
/PWMD: TP5.1, U1.1, U2.5 (PWMD)
/RML-: J3.3, Q2.3 (D)
/THRESH: C13.1, R7.1, U4.2 (TR), U4.6 (THR)
CLOCK: R8.2, TP4.1, U4.3 (Q), U6.1
GND: C1.1, C2.2, C3.2, C4.2, C9.1, C11.2, C12.2, C13.2, J3.4, Q2.2 (S), U3.3, U4.1 (GND), U5.1 (GND), U6.3 (GND)
GNDPWR: C5.2, C6.2, C10.2, D2.2 (A), J1.1, R10.2, R13.2, R15.1, R17.2, U1.2 (V-), U2.3 (GND)
unnamed: C7.2, C8.2, L1.5 (Out), L1.6 (Out), L1.7 (Out), L1.8 (Out), U3.2
unnamed: D1.2 (A), L1.1 (In), L1.2 (In), L1.3 (In), L1.4 (In), Q1.3 (D)
unnamed: D2.1 (K), R9.2, R10.1, U1.3 (+)
unnamed: Q1.1 (G), R19.2
unnamed: Q1.2 (S), R13.1, U2.2 (CS)
unnamed: Q2.1 (G), R6.2
unnamed: R5.2, TP2.1, U3.4, U6.2
unnamed: R6.1, TP3.1, U6.4
unnamed: R7.2, R8.1
unnamed: R9.1, R18.2
unnamed: R16.2, R17.1, U1.4 (-)
unnamed: R19.1, U2.4 (GATE)
unnamed: R15.2, U2.8 (RT)
TS+: C5.1, C6.1, C7.1, C8.1, D1.1 (K), J1.2, J2.2, R18.1, TP1.1, U2.1 (VIN)

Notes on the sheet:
555 Timer- 5hz 50% duty cycle
Mounting Holes
0.275/0.02 ~=13.7 ohm
PWMD LOW = LED OFF
60V->5V Trigger Comparator
falstad: https://tinyurl.com/29v9662o
low power, low vd
LV 12V->5V LDO
Connections

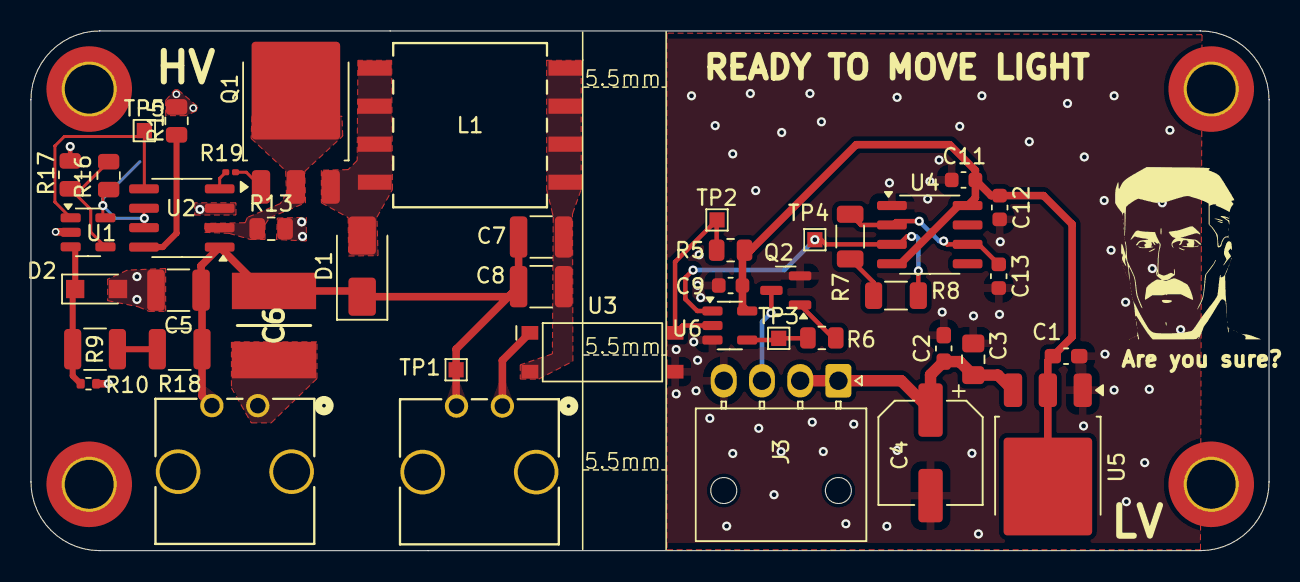
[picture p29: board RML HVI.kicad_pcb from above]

Board: 2 copper layers, 81.0 x 34.0 mm, 48 parts (1 on the bottom side), 24 nets.

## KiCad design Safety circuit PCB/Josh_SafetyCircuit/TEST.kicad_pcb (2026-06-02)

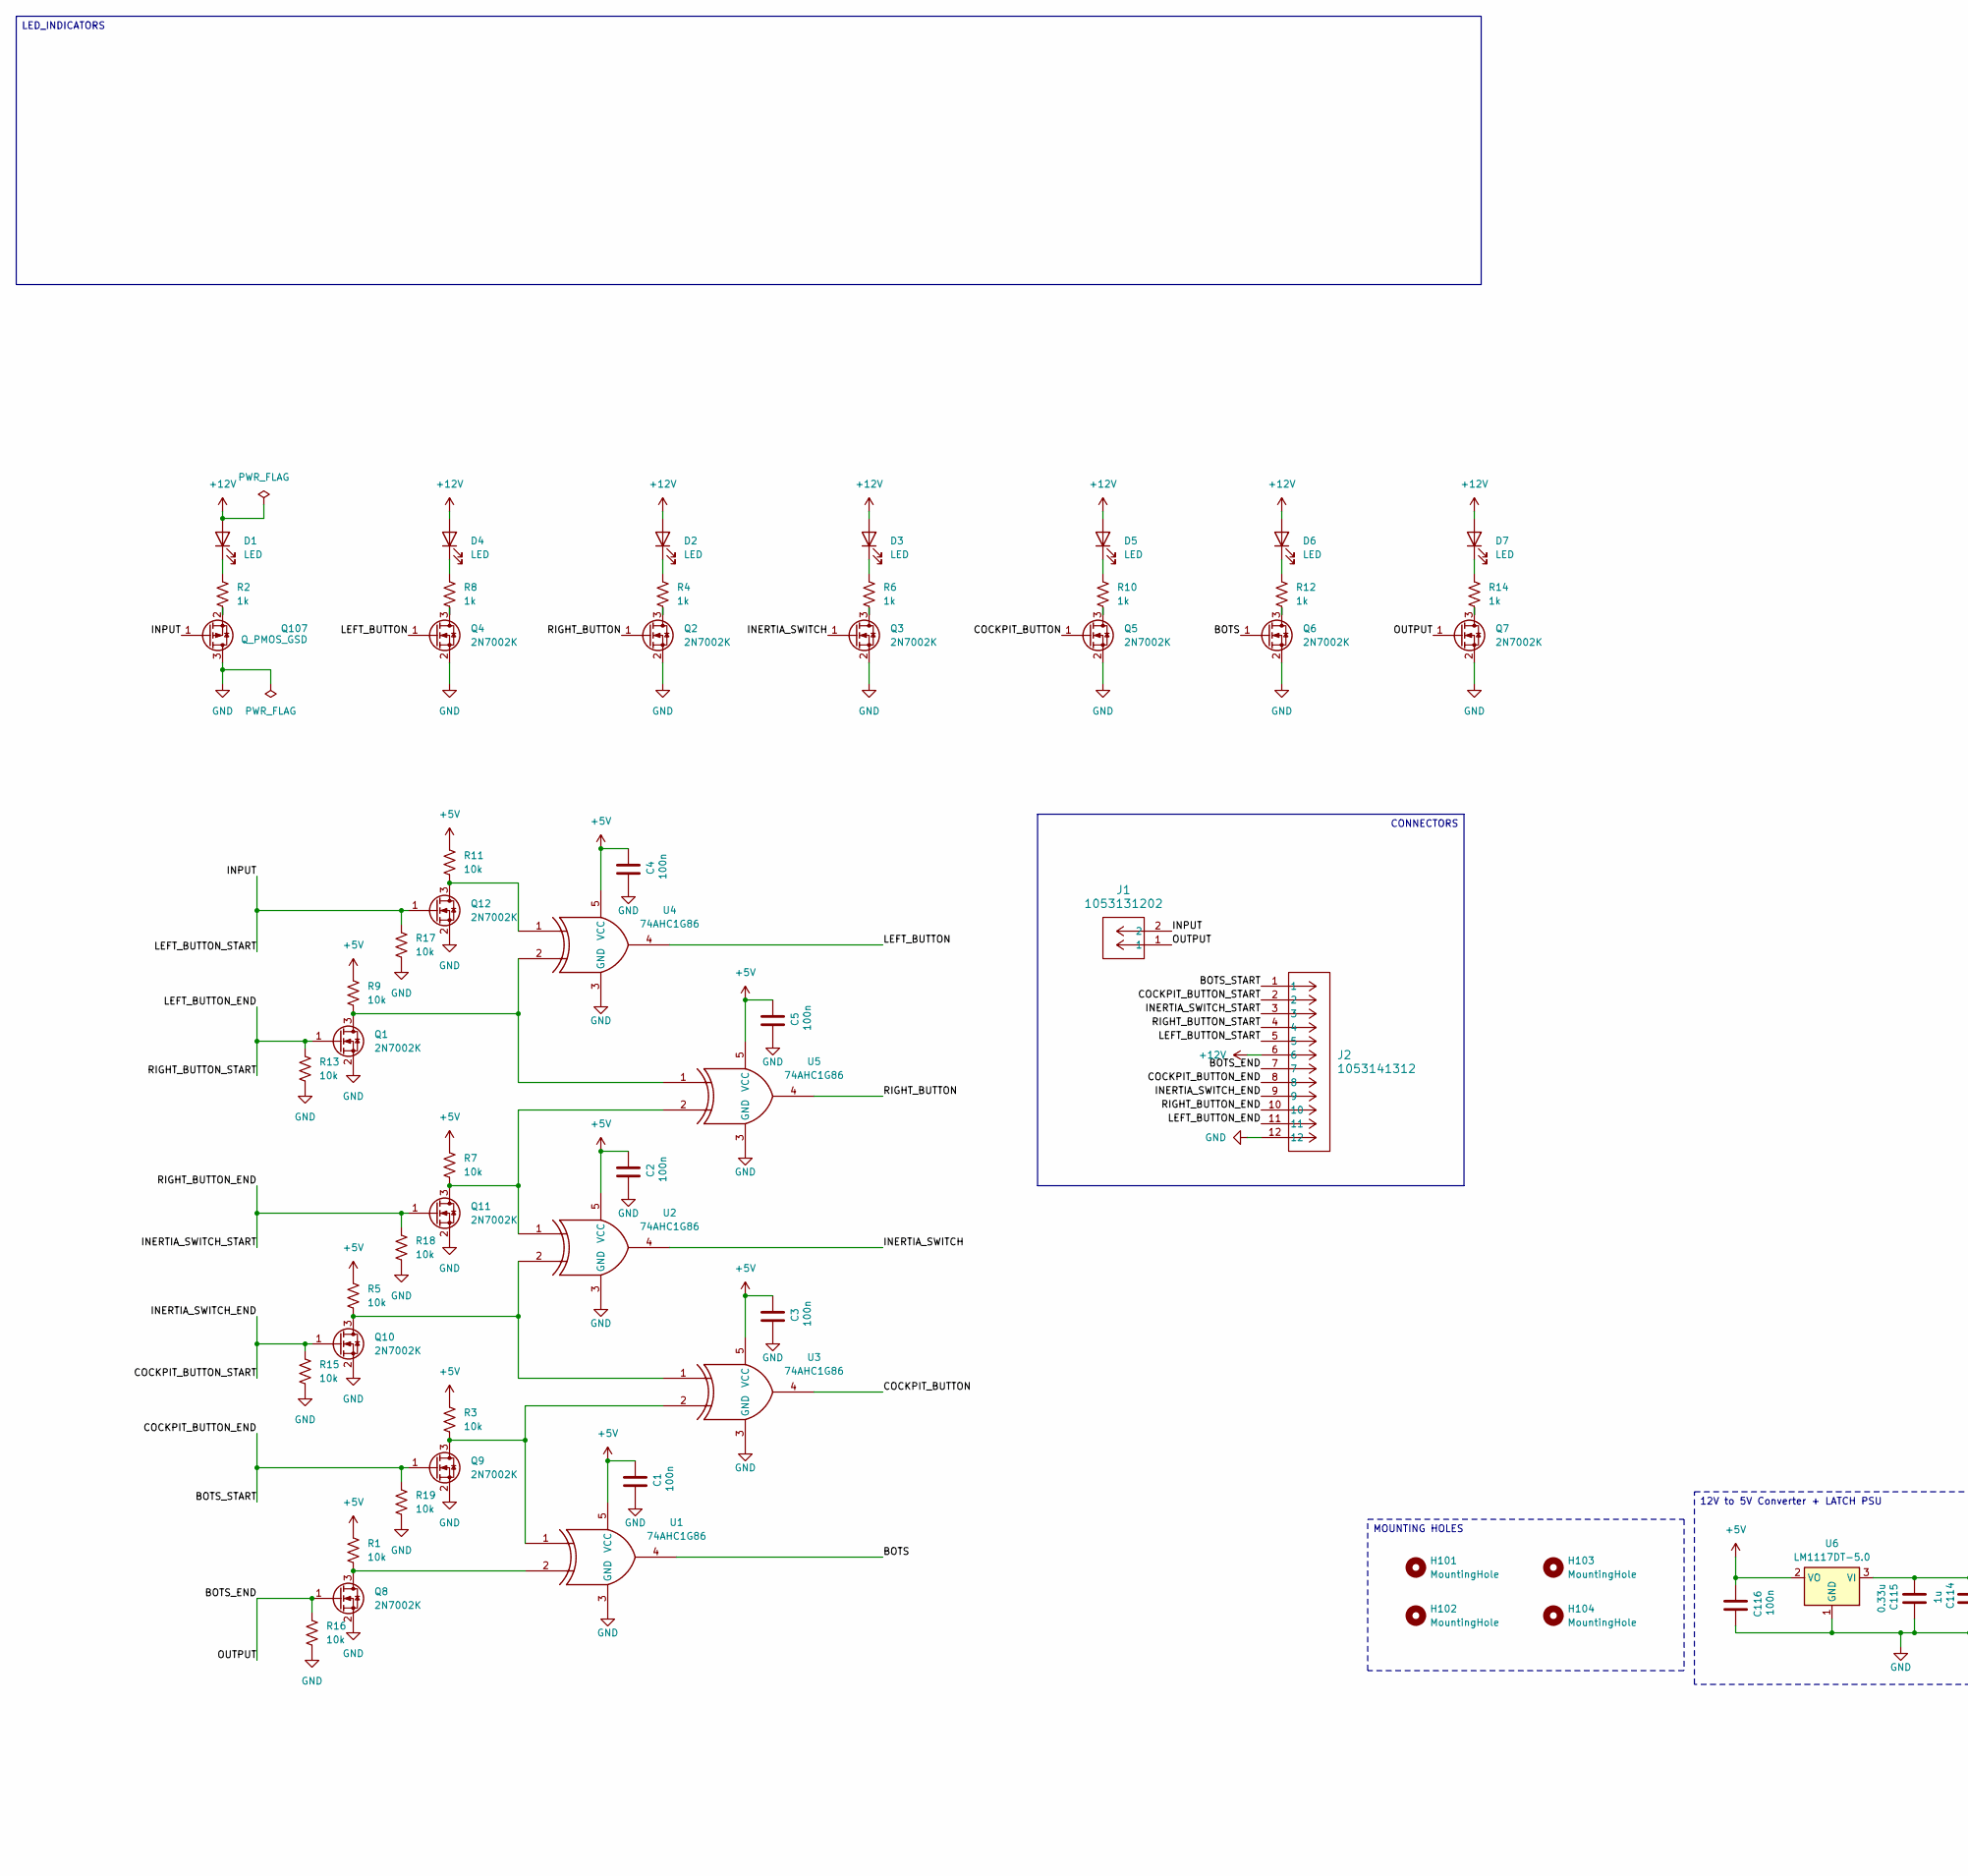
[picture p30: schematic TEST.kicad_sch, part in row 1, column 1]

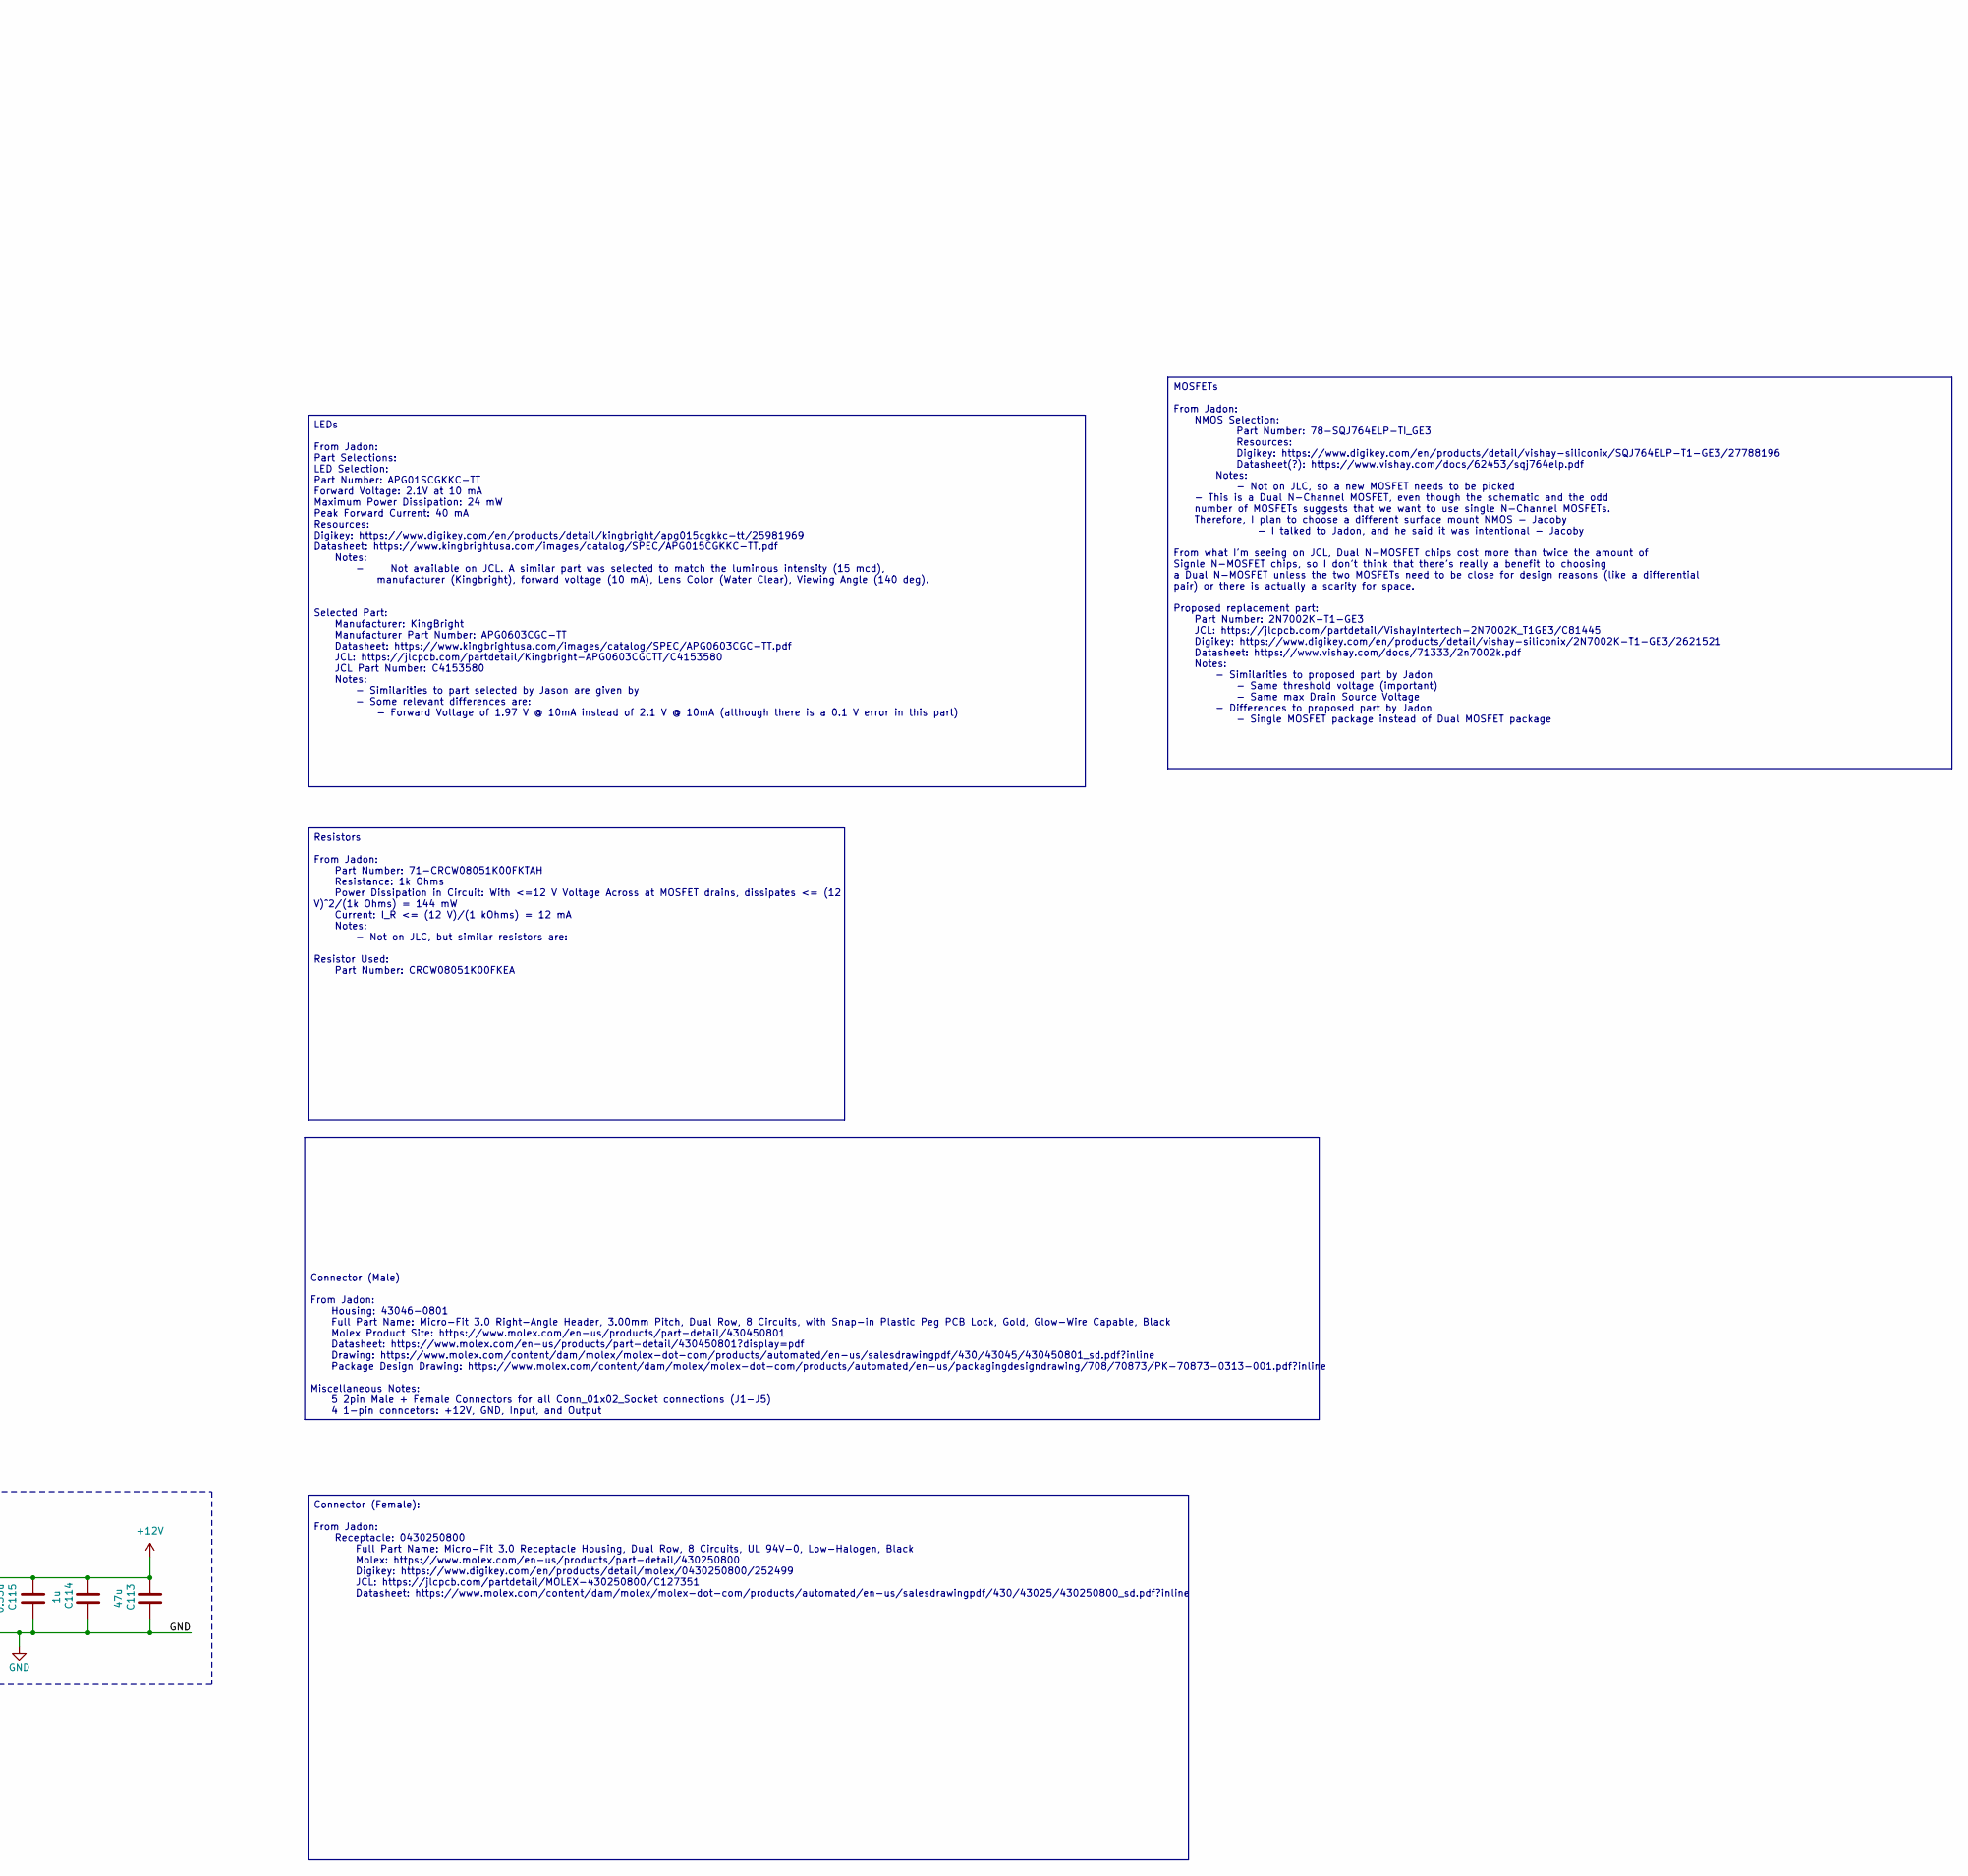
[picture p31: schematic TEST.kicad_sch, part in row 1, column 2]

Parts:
C1, C2, C3, C4, C5, C116: 100n; C_0603_1608Metric_Pad1.08x0.95mm_HandSolder; JLC# C1591
C113: 47u; CP_Elec_6.3x5.4; JLC# C2836440
C114: 1u; C_0805_2012Metric_Pad1.18x1.45mm_HandSolder; JLC# C91186
C115: 0.33u; C_0603_1608Metric_Pad1.08x0.95mm_HandSolder; JLC# C282682
D1, D2, D3, D4, D5, D6, D7: LED; HL-PSC-1608U52GC-G4; MFR Part # PSC-1608U50GC-G4; JLC Part # C22371297
H101, H102, H103, H104: MountingHole; MountingHole_4.3mm_M4_DIN965_Pad_TopOnly
J1: 1053131202; CONN_SD-105313-100_02_MOL; MFR Part # 1053131202; JLC Part # C586242
J2: 1053141312; CONN_SD-105314-100_12_MOL; MFR Part # 1053141312; JLC Part # C17318123
Q1, Q2, Q3, Q4, Q5, Q6, Q7, Q8, Q9, Q10, Q11, Q12: 2N7002K; SOT-23; MFR Part # 2N7002K-T1-GE3; JLC Part # C81445
Q107: Q_PMOS_GSD; SOT-523; JLC# C96676
R1, R3, R5, R7, R9, R11, R13, R15, R16, R17, R18, R19: 10k; CRCW0805; MFR Part # CRCW08051K00FKEA; JLC Part # C844939
R2, R4, R6, R8, R10, R12, R14: 1k; CRCW0805; MFR Part # CRCW08051K00FKEA; JLC Part # C844939
U1, U2, U3, U4, U5: 74AHC1G86; SOT-23-5_HandSoldering
U6: LM1117DT-5.0; TO-252-3_TabPin2; JLC# C354068

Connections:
+5V: C1.2, C2.2, C3.2, C4.2, C5.2, C116.2, R1.1, R3.1, R5.1, R7.1, R9.1, R11.1, U1.5 (VCC), U2.5 (VCC), U3.5 (VCC), U4.5 (VCC), U5.5 (VCC), U6.2 (VO)
+12V: C113.1, C114.1, C115.1, D1.2 (A), D2.2 (A), D3.2 (A), D4.2 (A), D5.2 (A), D6.2 (A), D7.2 (A), J2.6, U6.3 (VI)
/BOTS: Q6.1 (G), U1.4
/BOTS_END: J1.1, J2.7, Q7.1 (G), Q8.1 (G), R16.1
/BOTS_START: J2.1, J2.8, Q9.1 (G), R19.1
/COCKPIT_BUTTON: Q5.1 (G), U3.4
/COCKPIT_BUTTON_START: J2.2, J2.9, Q10.1 (G), R15.1
/INERTIA_SWITCH: Q3.1 (G), U2.4
/INERTIA_SWITCH_START: J2.3, J2.10, Q11.1 (G), R18.1
/INPUT: J1.2, J2.5, Q12.1 (G), Q107.1 (G), R17.1
/LEFT_BUTTON: Q4.1 (G), U4.4
/LEFT_BUTTON_END: J2.4, J2.11, Q1.1 (G), R13.1
/RIGHT_BUTTON: Q2.1 (G), U5.4
GND: C1.1, C2.1, C3.1, C4.1, C5.1, C113.2, C114.2, C115.2, C116.1, J2.12, Q1.2 (S), Q2.2 (S), Q3.2 (S), Q4.2 (S), Q5.2 (S), Q6.2 (S), Q7.2 (S), Q8.2 (S), Q9.2 (S), Q10.2 (S), Q11.2 (S), Q12.2 (S), Q107.3 (D), R13.2, R15.2, R16.2, R17.2, R18.2, R19.2, U1.3 (GND), U2.3 (GND), U3.3 (GND), U4.3 (GND), U5.3 (GND), U6.1 (GND)
unnamed: D1.1 (K), R2.1
unnamed: D2.1 (K), R4.1
unnamed: D3.1 (K), R6.1
unnamed: D4.1 (K), R8.1
unnamed: D5.1 (K), R10.1
unnamed: D6.1 (K), R12.1
unnamed: D7.1 (K), R14.1
unnamed: Q1.3 (D), R9.2, U4.2, U5.1
unnamed: Q2.3 (D), R4.2
unnamed: Q3.3 (D), R6.2
unnamed: Q4.3 (D), R8.2
unnamed: Q5.3 (D), R10.2
unnamed: Q6.3 (D), R12.2
unnamed: Q7.3 (D), R14.2
unnamed: Q8.3 (D), R1.2, U1.2
unnamed: Q9.3 (D), R3.2, U1.1, U3.2
unnamed: Q10.3 (D), R5.2, U2.2, U3.1
unnamed: Q11.3 (D), R7.2, U2.1, U5.2
unnamed: Q12.3 (D), R11.2, U4.1
unnamed: Q107.2 (S), R2.2

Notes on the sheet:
12V to 5V Converter + LATCH PSU
MOUNTING HOLES
LEDs From Jadon: Part Selections: LED Selection: Part Number: APG01SCGKKC-TT Forward Voltage: 2.1V at 10 mA Maximum Power Dissipation: 24 mW Peak Forward Current: 40 mA Resources: Digikey: https://www.digikey.com/en/products/detail/kingbright/apg015cgkkc-tt/25981969 Datasheet: https://www.kingbrigh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
CONNECTORS
Connector (Male) From Jadon: Housing: 43046-0801 Full Part Name: Micro-Fit 3.0 Right-Angle Header, 3.00mm Pitch, Dual Row, 8 Circuits, with Snap-in Plastic Peg PCB Lock, Gold, Glow-Wire Capable, Black Molex Product Site: https://www.molex.com/en-us/products/part-detail/430450801 Datasheet: https://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
Connector (Female): From Jadon: Receptacle: 0430250800 Full Part Name: Micro-Fit 3.0 Receptacle Housing, Dual Row, 8 Circuits, UL 94V-0, Low-Halogen, Black Molex: https://www.molex.com/en-us/products/part-detail/430250800 Digikey: https://www.digikey.com/en/products/detail/molex/0430250800/252499 J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
LED_INDICATORS
Resistors From Jadon: Part Number: 71-CRCW08051K00FKTAH Resistance: 1k Ohms Power Dissipation in Circuit: With <=12 V Voltage Across at MOSFET drains, dissipates <= (12 V)^2/(1k Ohms) = 144 mW Current: I_R <= (12 V)/(1 kOhms) = 12 mA Notes: - Not on JLC, but similar resistors are: Resistor Used: Pa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
MOSFETs From Jadon: NMOS Selection: Part Number: 78-SQJ764ELP-TI_GE3 Resources: Digikey: https://www.digikey.com/en/products/detail/vishay-siliconix/SQJ764ELP-T1-GE3/27788196 Datasheet(?): https://www.vishay.com/docs/62453/sqj764elp.pdf Notes: - Not on JLC, so a new MOSFET needs to be picked - This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

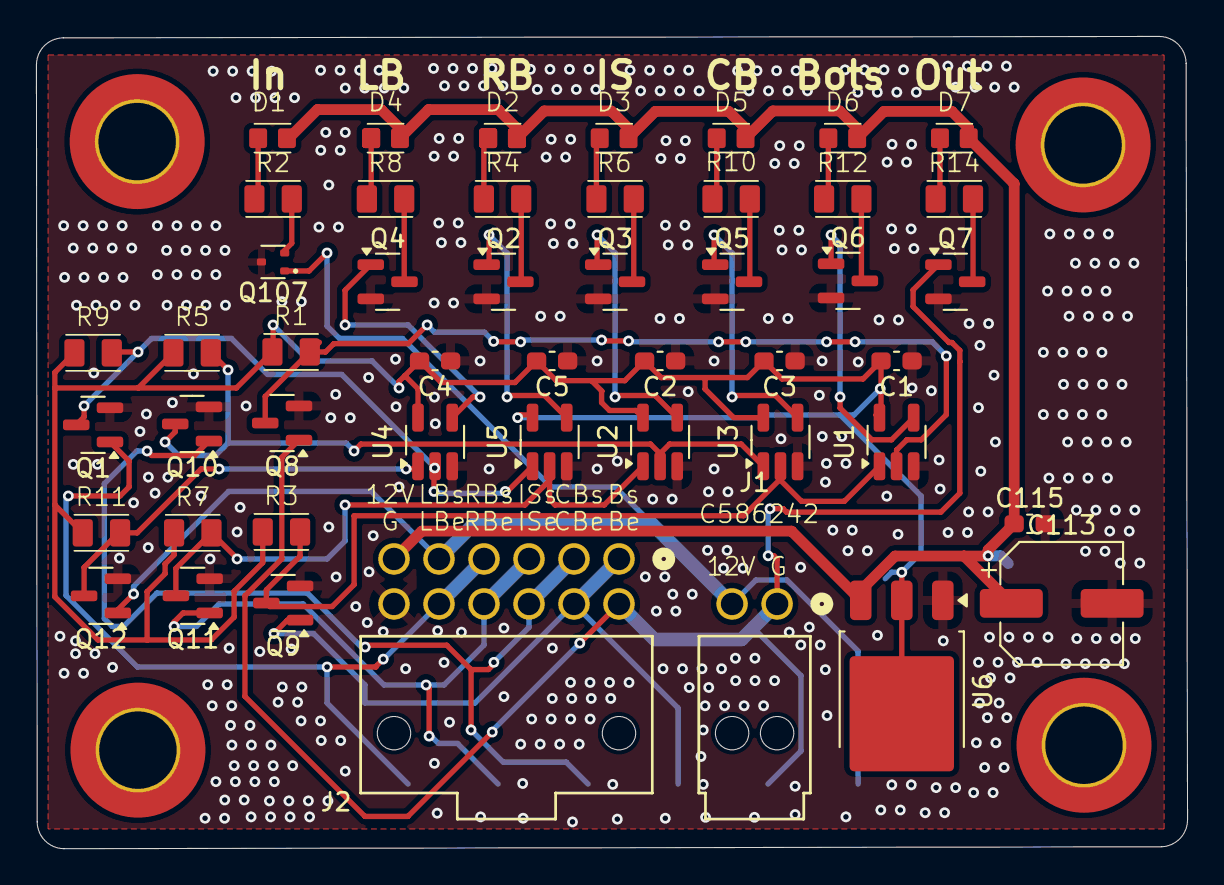
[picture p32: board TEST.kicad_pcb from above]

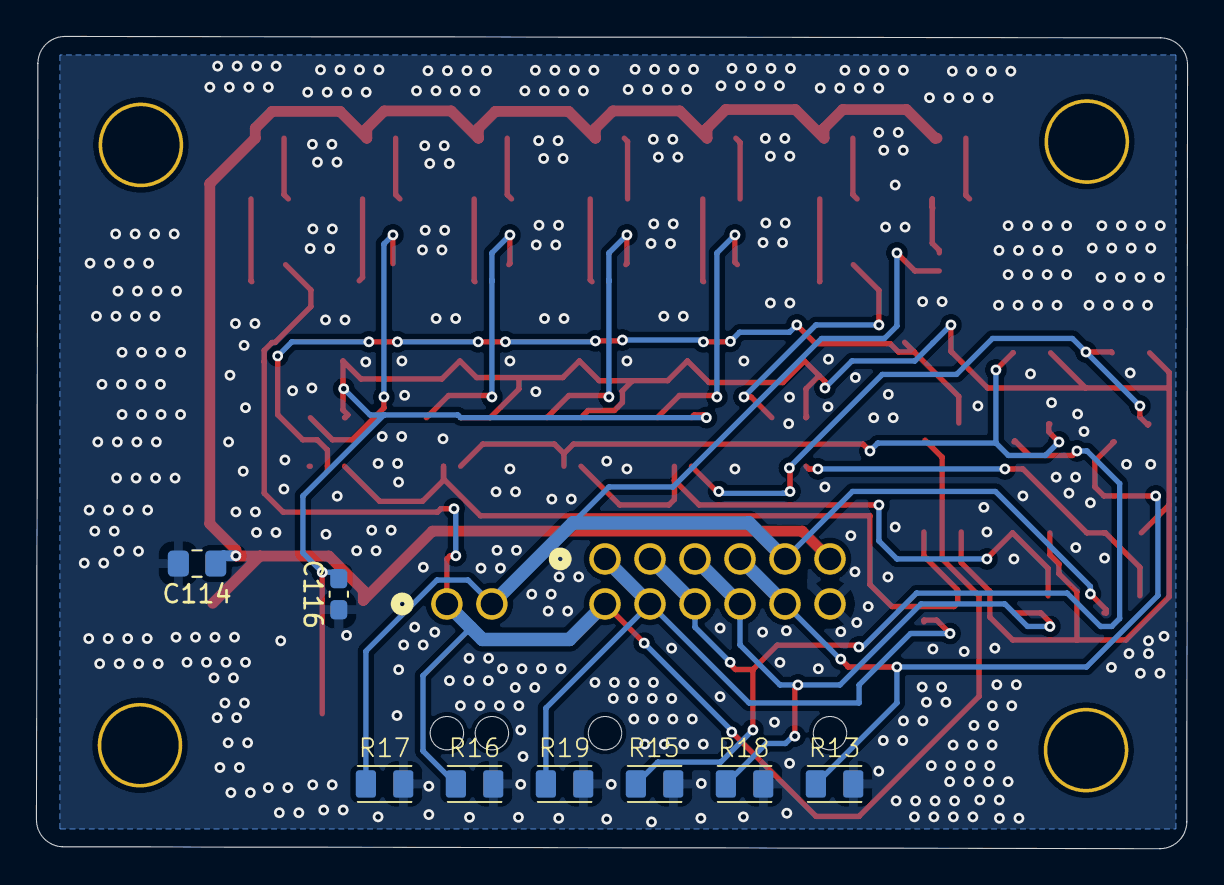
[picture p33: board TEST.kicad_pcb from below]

Board: 2 copper layers, 63.9 x 45.1 mm, 60 parts (8 on the bottom side), 34 nets.

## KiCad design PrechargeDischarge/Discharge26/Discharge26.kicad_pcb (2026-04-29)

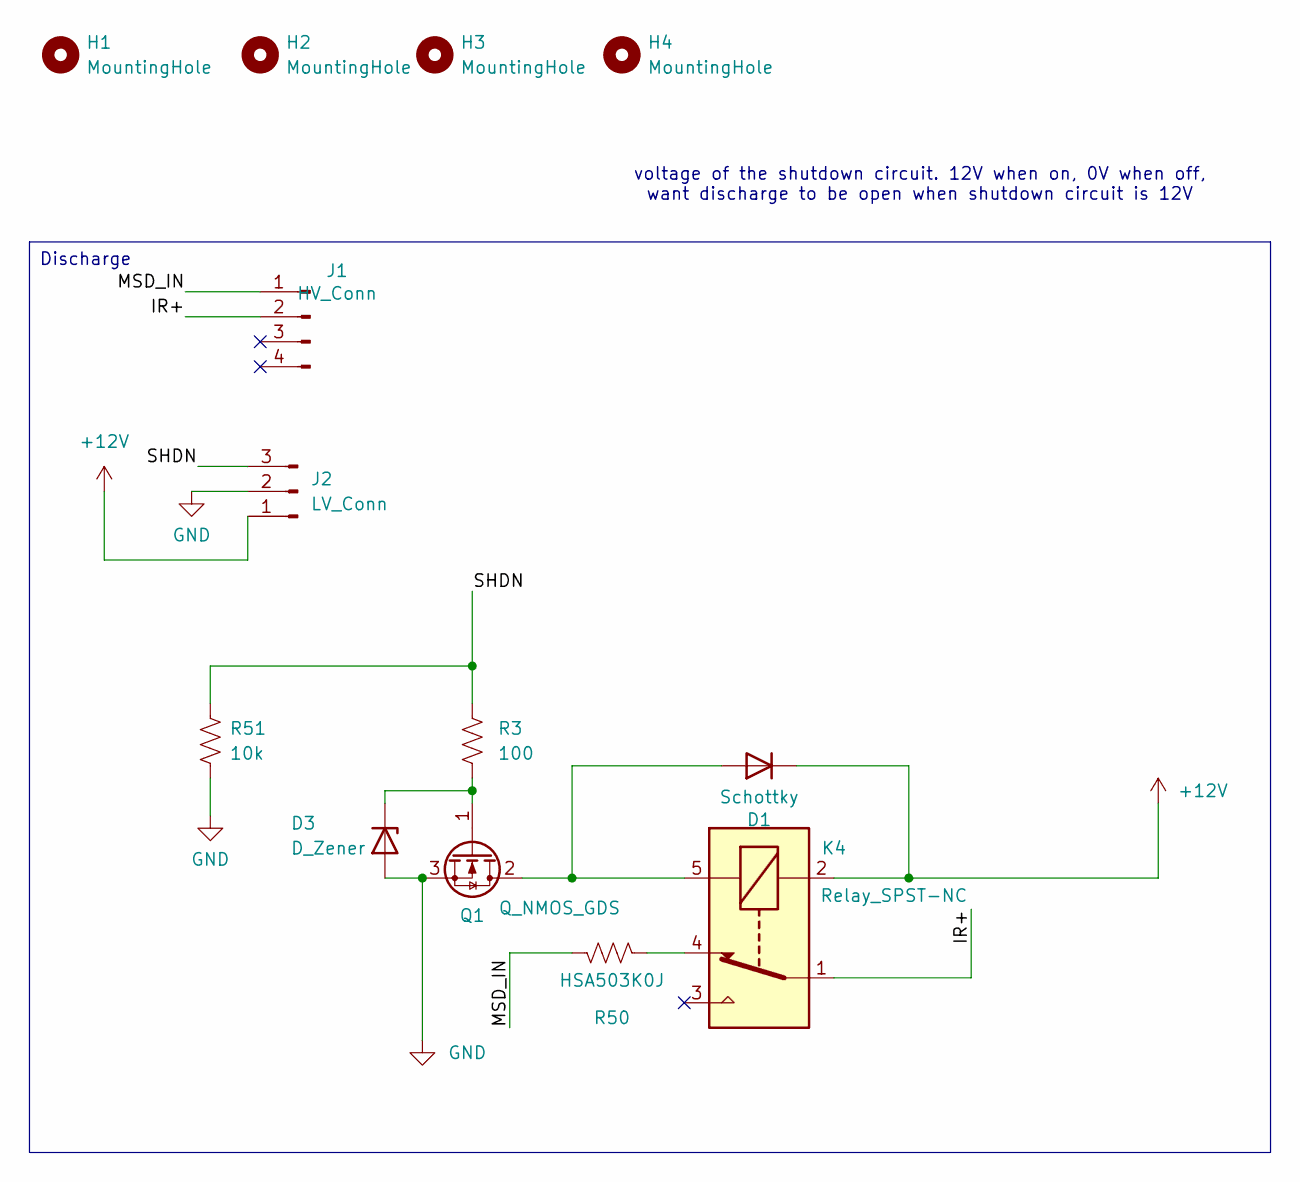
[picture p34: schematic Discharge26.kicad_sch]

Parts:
D1: Schottky; D_SMA; JLC C8678
D3: D_Zener; D_SOD-123; JLC C241967
H1, H2, H3, H4: MountingHole; MountingHole_4.3mm_M4
J1: HV_Conn; MicroFit_4pin
J2: LV_Conn; Molex_Nano-Fit_105313-xx03_1x03_P2.50mm_Horizontal; JLC C561764
K4: Relay_SPST-NC; Discharge_relay
Q1: Q_NMOS_GDS; TO-251-3_Vertical; JLC C3278986
R3: 100; R_0805_2012Metric_Pad1.20x1.40mm_HandSolder; JLC C17408
R50: HSA503K0J; Discharge_Resistor
R51: 10k; R_1206_3216Metric

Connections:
+12V: D1.1 (K), J2.1, K4.2
/IR+: J1.2, K4.1
/MSD_IN: J1.1, R50.2
/SHDN: J2.3, R3.1, R51.1
GND: D3.2 (A), J2.2, Q1.3 (S), R51.2
unnamed: D1.2 (A), K4.5, Q1.2 (D)
unnamed: D3.1 (K), Q1.1 (G), R3.2
unnamed: K4.4, R50.1

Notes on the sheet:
voltage of the shutdown circuit. 12V when on, 0V when off, want discharge to be open when shutdown circuit is 12V
Discharge


Board: 2 copper layers, 80.0 x 105.0 mm, 13 parts (0 on the bottom side), 8 nets.

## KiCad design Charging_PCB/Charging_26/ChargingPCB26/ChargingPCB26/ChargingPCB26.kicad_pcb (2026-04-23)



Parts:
C3, C117: 100n; C_0603_1608Metric_Pad1.08x0.95mm_HandSolder; MPN CL10B104KB8NNNC; JLC# C1591
C101, C102, C106: 0.01u; C_0402_1005Metric; MPN CL05B103KB5NNNC; JLC# C15195
C105: 0.33u; C_0402_1005Metric; MPN CC0402KRX5R6BB334; JLC# C107013
D1, D2: LED; LED_0805_2012Metric_Pad1.15x1.40mm_HandSolder; MPN NCD0805R1; JLC# C84256
D3: LED GREEN; LED_0805_2012Metric_Pad1.15x1.40mm_HandSolder; MPN KT-0805G; JLC# C2297
D4, D101, D102: D_Schottky; D_SMA; MPN SS34; JLC# C8678
F1: Fuse; Fuseholder_Blade_Mini_Keystone_3568; Digikey 36-3568-ND; not fitted
H101, H102, H103, H104: MountingHole; MountingHole_2.2mm_M2; not fitted
J1, J2: Molex6pin; Molex_Nano-Fit_105314-xx06_2x03_P2.50mm_Horizontal; MPN 1053141106; Digikey WM3802-ND
K101, K102: Relay_SPDT_Omron_G2RL-1; MPN G2RL-1-DC12; JLC# C469130
Q1, Q2, Q3, Q4: Q_NMOS_GDS; TO-251-3_Vertical; JLC# C3278986
Q103, Q104, Q105, Q106: Q_NPN_BEC; SOT-23; MPN S8050 J3Y(RANGE:200-350); JLC# C2146
R1, R2, R8, R10, R105, R106: 10k; R_0805_2012Metric_Pad1.20x1.40mm_HandSolder; MPN 0805W8F1002T5E; JLC# C17414
R3, R4, R9: 500; R_0805_2012Metric_Pad1.20x1.40mm_HandSolder; MPN ARG05BTC5000; JLC# C2828711
R5, R6, R13: 1k; R_0805_2012Metric_Pad1.20x1.40mm_HandSolder; MPN 0805W8F1001T5E; Digikey 1.00KXBK-ND
R7, R108, R109, R111, R113: 1k; R_0805_2012Metric_Pad1.20x1.40mm_HandSolder; MPN 0805W8F1001T5E; JLC# C17513
R11, R12: 100; R_0805_2012Metric_Pad1.20x1.40mm_HandSolder; JLC# C17408
R103, R104, R110, R112: 100k; R_0805_2012Metric_Pad1.20x1.40mm_HandSolder; MPN 0805W8F1003T5E; JLC# C149504
SW101, SW102: SW_Omron_B3FS; SW_SPST_Omron_B3FS-100xP; MPN B3FS-1000P; JLC# C271750
U1, U2: SFH617A-1; DIP-4_W7.62mm; MPN PC817X2NSZW; Digikey 58-SFH615A-1X-ND
U5: 74LS279; DIP-16_W7.62mm; MPN SN74LS279AN; Digikey 296-3684-5-ND
U6: 74HC00; DIP-14_W7.62mm; MPN SN74HC00N; JLC# C2902
U107: LM7805_TO220; TO-220-3_Vertical; MPN LM7805L-TF3-T; JLC# C71107

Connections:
+5V: C3.1, C106.1, C117.1, R1.1, R2.1, R3.1, R4.1, R9.1, R108.1, R109.1, R110.1, R111.1, R112.1, R113.1, SW101.2, SW102.2, U5.5 (~R), U5.6 (~S), U5.14 (~R), U5.15 (~S), U5.16 (VCC), U6.14 (VCC), U107.3 (VO)
+12V: C105.1, D4.1 (K), D101.1 (K), D102.1 (K), F1.1, J1.2, J1.3, J2.2, K101.A2, K102.11, K102.A2, R7.1, R13.1, U107.1 (VI)
/+12V_LVB: F1.2, J2.1
/-12V_Contactor: D4.2 (A), J1.4, Q3.2 (D)
/BMS_CSO: J1.6, R7.2, U1.1
/BMS_LV: R1.2, U1.4, U5.1 (~R), U6.5
/BMS_RESET: Q104.3 (C), R111.2, U6.4
/Charger_SHDN: J1.5, J2.3, K101.14, R8.1, R10.1, R11.1, R12.1
/IMD_LV: R2.2, U2.4, U5.10 (~R), U6.2
/IMD_OKhs: J1.1, R5.1, U2.2
/IMD_RESET: Q106.3 (C), R113.2, U6.1
GND: C3.2, C105.2, C106.2, C117.2, J2.4, J2.5, J2.6, Q1.3 (S), Q2.3 (S), Q3.3 (S), Q4.3 (S), Q103.2 (E), Q104.2 (E), Q105.2 (E), Q106.2 (E), R5.2, R6.2, R8.2, R10.2, R103.2, R104.2, U1.3, U2.3, U5.8 (GND), U6.7 (GND), U6.9, U6.10, U6.12, U6.13, U107.2 (GND)
unnamed: D1.2 (A), R3.2
unnamed: D1.1 (K), Q2.1 (G), U5.4 (Q)
unnamed: D2.2 (A), R4.2
unnamed: D2.1 (K), Q1.1 (G), U5.9 (Q)
unnamed: D3.2 (A), R9.2
unnamed: D3.1 (K), Q4.2 (D)
unnamed: D101.2 (A), K101.A1, Q2.2 (D)
unnamed: D102.2 (A), K102.A1, Q1.2 (D)
unnamed: K101.11, K102.14
unnamed: Q3.1 (G), R11.2
unnamed: Q4.1 (G), R12.2
unnamed: Q103.1 (B), R105.1
unnamed: C101.1, Q103.3 (C), R108.2
unnamed: C101.2, Q104.1 (B), R110.2
unnamed: Q105.1 (B), R106.1
unnamed: C102.1, Q105.3 (C), R109.2
unnamed: C102.2, Q106.1 (B), R112.2
unnamed: R6.1, U1.2
unnamed: R13.2, U2.1
unnamed: R103.1, R105.2, SW101.1
unnamed: R104.1, R106.2, SW102.1
unnamed: U5.2 (~S), U5.3 (~S), U6.6
unnamed: U5.11 (~S), U5.12 (~S), U6.3

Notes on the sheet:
Power Connections
Signal Connections/Accumulator Power
BMS Fault Pulls High (Pulls low when ready, DataSheet Linked)
IMD Fault Pulls Low (Data sheet linked)
Contactor Driver (Low side)
IMD SIGNAL INFO
UNUSED FROM SR LATCH/QUAD NAND GATE
5v Regulator, max input 35v
Mounting Holes
BMS SIGNAL INFO
BMS_ChargingShutdown
Pulse Generator Button BMS
Docs
IMD_ChargingShutdown
LED Indicator Driver
12V_Regulator, SR Latch input, Quad NAND Power
Wire to Board Connections (Outputs are AccumulatorLV,Shutdown,RML)
Pulse Generator Button IMD
https://tinyurl.com/2bfby7jn


Board: 2 copper layers, 100.0 x 100.0 mm, 59 parts (0 on the bottom side), 35 nets.

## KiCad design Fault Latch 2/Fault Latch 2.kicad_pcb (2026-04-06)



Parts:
C1, C116, C117: 100n; C_0603_1608Metric_Pad1.08x0.95mm_HandSolder; JLC# C1591
C2, C3, C5, C6, C108, C112, C118: 0.1u; C_0402_1005Metric; JLC# C133086
C4, C107: 1u; C_0402_1005Metric; JLC# C59782
C101, C105, C106: 10n; C_0603_1608Metric_Pad1.08x0.95mm_HandSolder; JLC# C1589
C109: .01u; C_0402_1005Metric; JLC# C15195
C111: 22u; C_0402_1005Metric; JLC# C105226
C113: 47u; CP_Elec_6.3x5.4; JLC# C2836440
C114: 1u; C_0805_2012Metric_Pad1.18x1.45mm_HandSolder; JLC# C91186
C115: 0.33u; C_0603_1608Metric_Pad1.08x0.95mm_HandSolder; JLC# C282682
D1, D2, D3: Bi-TVS Diode; D_SOD-523; Mouser# 750-CPDUR12V-HF; JLC# C2443698
D102, D107, D109: RED; LED_0805_2012Metric_Pad1.15x1.40mm_HandSolder; JLC# C19171391
D104, D108, D110: D_Schottky; D_SMA; JLC# C8678
H101, H102, H103, H104: MountingHole; MountingHole_4.3mm_M4_DIN965_Pad_TopOnly
IC1: CD4027BE; DIP794W53P254L1930H508Q16N; Mouser Part Number 595-CD4027BE
J1: 1053141312; CONN_SD-105314-100_12_MOL_Nano; MOUSER 538-105314-1312
J2: 4pinNanofit; Molex_Nano-Fit_105313-xx04_1x04_P2.50mm_Horizontal
J4: 1053131202; Molex_Nano-Fit_105313-xx02_1x02_P2.50mm_Horizontal; MOUSER 538-105313-1202
K1, K2, K3: Relay_SPDT_Omron_G2RL-1; MPN G2RL-1-DC12; JLC# C469130
Q3, Q4, Q105, Q106, Q112, Q113, Q114, Q115, Q117, Q118, Q120: Q_NMOS_GSD; SOT-23; JLC# C151421
Q101, Q102, Q103, Q104, Q110, Q111: Q_NPN_BEC; SOT-23; JLC# C2146
R1, R4, R7, R9, R12, R105, R114, R121, R123, R136: 10k; R_1210_3225Metric; JLC# C137088
R2, R6, R8, R108, R111, R115, R120, R124, R129: 1k; R_1210_3225Metric; JLC# C230096
R3, R130, R150: 270R; R_1210_3225Metric; JLC# C230144
R5: 2.2k; R_2512_6332Metric; Mouser Part Number AC2512JK-072K2L; JLC# C231008
R10, R13, R112: 510R; R_1210_3225Metric; JLC# C230277
R101, R110, R113, R119, R122, R127, R132: 100k; R_1210_3225Metric; JLC# C230004
R117, R128, R137: 2k; R_1210_3225Metric; JLC# C137097
R133: 680; R_1210_3225Metric; JLC# C137071
R141: 5.6k; R_1210_3225Metric; JLC# C230478
SW101, SW102, SW103: SW_Omron_B3FS; SW_SPST_Omron_B3FS-100xP; JLC# C271750
TP1, TP2, TP3, TP4, TP5, TP6, TP7, TP8, TP9, TP10, TP11, TP12: TestPoint; TestPoint_Pad_D1.5mm
U1: 74LS279; DIP-16_W7.62mm; MOUSER 595-SN74LS279ADR
U2: LM1117DT-5.0; TO-252-3_TabPin2; JLC# C354068
U3, U5, U6: SFH617A-1; DIP-4_W7.62mm; JLC# C5350
U4: 74HC00; DIP-14_W7.62mm; MPN SN74HC00N; JLC# C2902
U7, U8: SN74AHC1G08DBVR; SOT-23-5; JLC# C7467
U118: LM555xM; SOIC-8_3.9x4.9mm_P1.27mm; Mouser Part Number 926-LMC555CMX/NOPB; JLC# C90760

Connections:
+5V: C1.1, C4.1, C5.1, C107.1, C108.1, C112.2, C116.2, C117.1, C118.2, IC1.10 (J1), IC1.11 (K1), IC1.16 (VDD), J2.1, R1.1, R108.1, R110.1, R111.1, R115.1, R117.2, R119.1, R120.1, R124.1, R127.1, R128.2, R129.1, R132.2, R137.2, SW101.2, SW102.2, SW103.2, U1.16 (VCC), U2.2 (VO), U3.4, U4.14 (VCC), U6.4, U7.5 (VCC), U8.5 (VCC), U118.4 (R), U118.8 (VCC)
+12V: C113.1, C114.1, C115.1, D104.1 (K), D108.1 (K), D110.1 (K), J1.7, K1.A1, K2.A1, K3.A1, R2.1, R12.1, R121.1, R136.1, U2.3 (VI)
/BMS: C2.1, D1.2 (A2), J1.12, R2.2, U5.1
/BMS Button -: J2.4, R101.1, R105.2, SW101.1
/BMS Light -: J1.4, R10.1
/BMS_SR: D102.1 (K), Q114.1 (G), Q117.1 (G), TP7.1, U1.4 (Q), U4.13, U8.1
/BSPD: C6.1, D3.2 (A2), J4.2, R7.1, U3.1
/BSPD Button -: J2.2, R122.1, R123.2, SW103.1
/BSPD Light -: J1.11, R13.1
/BSPD_SR: D109.1 (K), Q3.1 (G), Q120.1 (G), TP12.1, U1.9 (Q)
/CLOCK: IC1.15 (Q1), U7.2
/IMD: C3.1, D2.2 (A2), J1.6, R5.1, U6.1
/IMD Button -: J2.3, R113.1, R114.2, SW102.1
/IMD Light -: J1.10, R112.1
/IMD_SR: D107.1 (K), Q105.1 (G), Q118.1 (G), TP10.1, U1.7 (Q), U4.12, U8.2
/NBMS_LV: R1.2, TP5.1, U1.1 (~R), U4.1, U5.4
/NBPSD_LV: R9.1, TP9.1, U1.10 (~R), U3.3, U4.9
/NIMD_LV: R4.1, TP8.1, U1.5 (~R), U4.4, U6.3
/NRESET_BMS: Q102.3 (C), R111.2, TP1.1, U4.2
/NRESET_BSPD: Q111.3 (C), R129.2, TP3.1, U4.10
/NRESET_IMD: Q104.3 (C), R120.2, TP2.1, U4.5
/Shutdown Circuit In: J1.2, K1.14
/Shutdown Circuit Out: J1.8, K3.11, TP6.1
/THRESH: C111.2, R132.1, R141.2, U118.2 (TR), U118.6 (THR)
/TSSI Green -: J1.9, R130.2
/TSSI Red -: J1.3, R150.2
GND: C1.2, C4.2, C5.2, C107.2, C108.2, C109.2, C111.1, C112.1, C113.2, C114.2, C115.2, C116.1, C117.2, C118.1, D1.1 (A1), D2.1 (A1), D3.1 (A1), IC1.3 (CLOCK2), IC1.4 (RESET2), IC1.5 (K2), IC1.6 (J2), IC1.7 (SET2), IC1.8 (VSS), IC1.9 (SET1), IC1.12 (RESET1), J1.1, Q3.2 (S), Q4.2 (S), Q101.2 (E), Q102.2 (E), Q103.2 (E), Q104.2 (E), Q105.2 (S), Q106.2 (S), Q110.2 (E), Q111.2 (E), Q112.2 (S), Q113.2 (S), Q114.2 (S), Q115.2 (S), Q117.2 (S), Q118.2 (S), Q120.2 (S), R3.1, R4.2, R5.2, R6.2, R7.2, R8.2, R9.2, R101.2, R113.2, R122.2, U1.8 (GND), U2.1 (GND), U4.7 (GND), U5.3, U7.3 (GND), U8.3 (GND), U118.1 (GND)
unnamed: C2.2, R3.2, U5.2
unnamed: C3.2, R6.1, U6.2
unnamed: C6.2, R8.1, U3.2
unnamed: D102.2 (A), R117.1
unnamed: D104.2 (A), K1.A2, Q117.3 (D)
unnamed: D107.2 (A), R128.1
unnamed: D108.2 (A), K2.A2, Q118.3 (D)
unnamed: D109.2 (A), R137.1
unnamed: D110.2 (A), K3.A2, Q120.3 (D)
unnamed: IC1.13 (CLOCK1), R141.1, U118.3 (Q)
unnamed: K1.11, K2.14, TP4.1
unnamed: K2.11, K3.14, TP11.1
unnamed: Q3.3 (D), Q4.1 (G), R12.2
unnamed: Q4.3 (D), R13.2
unnamed: Q101.1 (B), R105.1
unnamed: C101.1, Q101.3 (C), R108.2
unnamed: C101.2, Q102.1 (B), R110.2
unnamed: Q103.1 (B), R114.1
unnamed: C105.1, Q103.3 (C), R115.2
unnamed: C105.2, Q104.1 (B), R119.2
unnamed: Q105.3 (D), Q106.1 (G), R121.2
unnamed: Q106.3 (D), R112.2
unnamed: Q110.1 (B), R123.1
unnamed: C106.1, Q110.3 (C), R124.2
unnamed: C106.2, Q111.1 (B), R127.2
unnamed: Q112.3 (D), R130.1
unnamed: Q112.1 (G), U8.4
unnamed: Q113.3 (D), R150.1
unnamed: Q113.1 (G), R133.1
unnamed: Q114.3 (D), Q115.1 (G), R136.2
unnamed: Q115.3 (D), R10.2
unnamed: R133.2, U7.4
unnamed: U1.2 (~S), U1.3 (~S), U4.3
unnamed: U1.6 (~S), U4.6
unnamed: U1.11 (~S), U1.12 (~S), U4.8
unnamed: U4.11, U7.1
unnamed: C109.1, U118.5 (CV)

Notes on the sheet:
16mA MAX
BMS Wiring Manual
When nR pulsed low (fault), Q pulled low Undefined when both inputs low
Click here for BMS and IMD Manual
BSPD is a separate pcb board
f = 1 / (0.693 * (2R106) * C102)
https://www.electronics-tutorials.ws/waveforms/555_oscillator.html
Click Here
UNUSED
Pulse Generator Button BMS
Inputs - Stuff in Boxes is what Fault latch does/has in the circuit
TSSI red
BSPD (12V When No Fault)
BMS (GND When No Fault)
Pulse Generator Button BSPD
TSSI Green
ASTABLE 555 - 50% DUTY - 2-5Hz
Fault Latch is part of Shutdown Circuit
Docs
Pulse Generator Button IMD
12V to 5V Converter + LATCH PSU
MOUNTING HOLES
BSPD LIGHT
Inputs - BMS active low, IMD and BPSD active 12V high
BMS LIGHT
IMD (12V When No Fault)
Falstad Simulation:
IMD LIGHT



Board: 2 copper layers, 85.8 x 94.2 mm, 119 parts (29 on the bottom side), 64 nets.

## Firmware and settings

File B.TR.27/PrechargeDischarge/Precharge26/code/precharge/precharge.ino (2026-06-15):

/*
  Precharge - Code to drive the NU Racing Precharge module (prototype)
  Created by Michael Ruppe
  April 2020

  Watch a primer video on this device here: https://youtu.be/6-RndXZ5mR4
  For more documentation, visit: https://github.com/michaelruppe/FSAE

  Dear future FSAE engineer,
  Perform a find (Ctrl+f) for "TODO" to see if I left you any surprises :D

  Commissioning notes:
    - Make sure TARGET_PERCENT is sensible (95%). I set it much lower
      during prototyping.

  Features:
    - Voltage feedback ensures sufficient precharge before closing AIR
    - Wiring fault / stuck-discharge detection on "too-fast/slow" precharge
    - May arrest AIR chatter -> minimum precharge time triggers error state and
      requires uC reset or power cycle.


  Other Notes:
    - Consider adding a condition to the STATE_STANDBY -> STATE_PRECHARGE
      transition: Check for near-zero TS voltages ensures full discharge before
      attempting a precharge.
*/


#include "gpio.h"
#include "measurements.h"
#include "moving-average.h"
#include "states.h"

const float MIN_SDC_VOLTAGE = 3; // [Volts], updated 3/12 to accomodate for IR min Voltage of 7.5, and precharge min voltage of 9V on relay coils

// Exponential Moving Average Filters
MovingAverage TSV_Average(0, 0.1); // Tractive system Voltage
MovingAverage ACV_Average(0, 0.1); // Accumulator (upstream of precharge resistor)
MovingAverage SDC_Average(0, 0.5); // Shutdown Circuit

STATEVAR state = STATE_STANDBY;
STATEVAR lastState = STATE_UNDEFINED;
int errorCode = ERR_NONE;

StatusLight statusLED[4] {{ STATUS_LED[0] },
                          { STATUS_LED[1] },
                          { STATUS_LED[2] },
                          { STATUS_LED[3] }};

char lineBuffer[50];
unsigned long now; // Uptime from millis()

void setup() {
  Serial.begin(460800);
  setupGPIO();
  //delay(1000);  // TODO: remove during commissioning

}


void loop() {
  now = millis();

  // 1. ALWAYS monitor Shutdown Circuit 
  monitorShutdownCircuit();

  // 2. ALWAYS monitor High Voltage Sensors
  const unsigned long samplePeriod = 10; 
  static unsigned long lastHVSample = 0;
  if (now > lastHVSample + samplePeriod){ 
    lastHVSample = now;
    ACV_Average.update(getAccuVoltage());
    TSV_Average.update(getTsVoltage());
  }

  // 3. The State Machine
  switch(state){
    case STATE_STANDBY :
      standby();
      break;

    case STATE_PRECHARGE :
      precharge();
      break;

    case STATE_ONLINE :
      running();
      break;


    case STATE_ERROR :
      errorState();

    default : // You tried to enter a state not defined in this switch-case
      state = STATE_ERROR;
      errorCode |= ERR_STATE_UNDEFINED;
      errorState();
  }

  updateStatusLeds();

  // --- GLOBAL HARDWARE DEBUG PRINT ---, put back in when testing AIR and PC outputs
  //static unsigned long lastDebugPrint = 0;
  //if (now > lastDebugPrint + 500) { // Print every 500ms
  //  lastDebugPrint = now;
   // Serial.print(F("HARDWARE STATUS -> PC_PIN: "));
   // Serial.print(digitalRead(PRECHARGE_CTRL_PIN));
    //Serial.print(F(" | MAIN_AIR_PIN: "));
    //Serial.println(digitalRead(SHUTDOWN_CTRL_PIN));
  //}

}

void monitorShutdownCircuit() {
  static unsigned long lastSample = 0;
  if (now > lastSample + 10) {
    lastSample = now;
    SDC_Average.update(getShutdownCircuitVoltage());
  }
  // Error state should be deadlocked - no way out.
  if ( SDC_Average.value() < MIN_SDC_VOLTAGE && state != STATE_ERROR) {
    state = STATE_STANDBY;
  }
}

// Open AIRs, Open Precharge, indicate status, wait for stable shutdown circuit
void standby() {
  static unsigned long epoch;
  if (lastState != STATE_STANDBY) {
    lastState = STATE_STANDBY;
    statusLEDsOff();
    statusLED[0].on();
    Serial.println(F(" === STANDBY"));
    Serial.println(F("* Waiting for stable shutdown circuit"));
    epoch = millis(); // make sure to reset if we've circled back to standby

    // Reset moving averages
    // TSV_Average.reset();
    // ACV_Average.reset();
    // SDC_Average.reset();
  }

  // Disable AIR, Disable Precharge
  digitalWrite(PRECHARGE_CTRL_PIN, LOW);
  digitalWrite(SHUTDOWN_CTRL_PIN, LOW);

  // Check for stable shutdown circuit
  const unsigned int WAIT_TIME = 200; // ms to wait for stable voltage
  if (SDC_Average.value() >= MIN_SDC_VOLTAGE){
    if (millis() > epoch + WAIT_TIME){
      state = STATE_PRECHARGE;
    }
  } else {
    epoch = millis(); // reset timer
  }

}

// Close the precharge relay, monitor precharge voltage.
// Trip error if charge-time looks unusual
void precharge() {
  // Look for "too fast" or "too slow" precharge, indicates wiring fault
  const float MIN_EXPECTED = 1000; // [ms]. Set this to something reasonable after collecting normal precharge sequence data, change to 1000 when discharging, 0 when charging
  const float MAX_EXPECTED = 2000; // [ms]. Set this to something reasonable after collecting normal precharge sequence data
  // If a precharge is detected faster than this, an error is
  // thrown - assumed wiring fault. This could also arrest oscillating or
  // chattering AIRs, because the TS will retain some amount of precharge.
  const float TARGET_PERCENT = 90.0;   // TODO: Requires suitable value during commissioning (eg 95%)
  const unsigned int SETTLING_TIME = 150; // [ms] Precharge amount must be over TARGET_PERCENT for this long before we consider precharge complete
  static unsigned long epoch;
  static unsigned long tStartPre;

  if (lastState != STATE_PRECHARGE){
    digitalWrite(PRECHARGE_CTRL_PIN, HIGH);
    lastState = STATE_PRECHARGE;
    statusLEDsOff();
    statusLED[1].on();
    sprintf(lineBuffer, " === PRECHARGE   Target precharge %4.1f%%\n", TARGET_PERCENT);
    Serial.print(lineBuffer);
    epoch = now;
    tStartPre = now;
  }

   // Sample the voltages and update moving averages
  //const unsigned long samplePeriod = 10; // [ms] Period to measure voltages
  //static unsigned long lastSample = 0;
  //if (now > lastSample + samplePeriod){  // samplePeriod and movingAverage alpha value will affect moving average response.
   // lastSample = now;
   // ACV_Average.update(getAccuVoltage());
    //TSV_Average.update(getTsVoltage());
  //}
  // --- COMMENT OUT THE REAL SENSORS FOR BENCH TESTING ---
   double acv = ACV_Average.value(); 
   double tsv = TSV_Average.value();
  
 //double acv = 302.4; // ACV_Average.value() when Motor controller is in, 302.4 when charging/bench testing
 //double tsv = 302.4; //TSV_avg value() when MC is in, 302.4 when charging/bench

  // The precharge progress is a function of the accumulator voltage
  double prechargeProgress = 100.0 * tsv / acv; // [%]

  // Print Precharging progress
  static unsigned long lastPrint = 0;
  if (now >= lastPrint + 100) {
    lastPrint = now;
    sprintf(lineBuffer, "%5lums %4.1f%%   %5.1fV\n", now-tStartPre, prechargeProgress, TSV_Average.value());
    Serial.print(lineBuffer);
  }

  // Check if precharge complete
  if ( prechargeProgress >= TARGET_PERCENT ) {
    // Precharge complete
    if (now > epoch + SETTLING_TIME){
      state = STATE_ONLINE;
      sprintf(lineBuffer, "* Precharge complete at: %2.0f%%   %5.1fV\n", prechargeProgress, TSV_Average.value());
      Serial.print(lineBuffer);
    }
    else if (now < tStartPre + MIN_EXPECTED && now > epoch + SETTLING_TIME) {    // Precharge too fast - something's wrong!
      state = STATE_ERROR;
      errorCode |= ERR_PRECHARGE_TOO_FAST;
    }

  } else {
    // Precharging
    epoch = now;

    if (now > tStartPre + MAX_EXPECTED) {       // Precharge too slow - something's wrong!
      state = STATE_ERROR;
      errorCode |= ERR_PRECHARGE_TOO_SLOW;
    }
  }



}

void running() {
  const unsigned int T_OVERLAP = 500; // ms. Time to overlap the switching of AIR and Precharge
  static unsigned long epoch;
  if (lastState != STATE_ONLINE){
    statusLEDsOff();
    statusLED[2].on();
    Serial.println(F(" === RUNNING"));
    lastState = STATE_ONLINE;
    epoch = now;
  }

  digitalWrite(SHUTDOWN_CTRL_PIN, HIGH);
  if (now > epoch + T_OVERLAP) digitalWrite(PRECHARGE_CTRL_PIN, LOW);

}

void errorState() {
  digitalWrite(PRECHARGE_CTRL_PIN, LOW);
  digitalWrite(SHUTDOWN_CTRL_PIN, LOW);

  if (lastState != STATE_ERROR){
    lastState = STATE_ERROR;
    statusLEDsOff();
    statusLED[3].update(50,50); // Strobe STS LED
    Serial.println(F(" === ERROR"));

    // Display errors: Serial and Status LEDs
    if (errorCode == ERR_NONE){
      Serial.println(F("   *Error state, but no error code logged..."));
    }
    if (errorCode & ERR_PRECHARGE_TOO_FAST) {
      Serial.println(F("   *Precharge too fast. Suspect wiring fault / chatter in shutdown circuit."));
      statusLED[0].on();
    }
    if (errorCode & ERR_PRECHARGE_TOO_SLOW) {
      Serial.println(F("   *Precharge too slow. Potential causes:\n   - Wiring fault\n   - Discharge is stuck-on\n   - Target precharge percent is too high"));
      statusLED[1].on();
    }
    if (errorCode & ERR_STATE_UNDEFINED) {
      Serial.println(F("   *State not defined in The State Machine."));
    }
  }

}


// Loop through the array and call update.
void updateStatusLeds() {
  for (uint8_t i=0; i<(sizeof(statusLED)/sizeof(*statusLED)); i++){
    statusLED[i].update();
  }
}
void statusLEDsOff() {
  for (uint8_t i=0; i<(sizeof(statusLED)/sizeof(*statusLED)); i++){
    statusLED[i].off();
  }
}
void updateStatusLeds(long ton, long toff) {
  for (uint8_t i=0; i<(sizeof(statusLED)/sizeof(*statusLED)); i++){
    statusLED[i].update(ton, toff);
  }
}

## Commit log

2025-11-01 finished schematic and layout
    [BreathOf_fresh_Air.kicad_pcb, BreathOf_fresh_Air.kicad_sch, bom.csv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]
2026-03-17 changes mounting holes on discharge to M4
    gareth wants all pcb mounting holes to M4
    [Discharge26.kicad_pcb, Discharge26.kicad_sch]
2026-03-18 Discharge
    Added through hole mosfets and LED driver to DIscharge board
    [Discharge26.kicad_pcb, Discharge26.kicad_sch]
2026-03-25 vcu kicad filrd
    [MAIN VCU.kicad_pcb, MAIN VCU.kicad_sch]
2026-03-27 added power board
    [MP3437GRP.step, Power Board.kicad_pcb, Power Board.kicad_sch]
2026-03-30 discharge fixed
    added zener diode from nmos gate to source, also added indiactor LED
    [Discharge26.kicad_pcb, Discharge26.kicad_sch]
2026-03-31 Charging PCB 12V+ wire length increased
    [ChargingPCB26.kicad_pcb]
2026-03-31 Fault Latch Finished Schematic V4
    Finished revised schematic and started on layout.
    [Fault Latch 2.kicad_pcb, Fault Latch 2.kicad_sch]
2026-04-02 Fault Latch V4 (almost RTO needs mounting holes)
    Needs a final edge cut and mounting holes placed on it, besides that everything else is ready.
    [Fault Latch 2.kicad_pcb, Fault Latch 2.kicad_sch]
2026-04-02 Fault Latch RTO V4
    Ready to order might push a different one with more sketches for final order.
    [Fault Latch 2.kicad_pcb, Fault Latch 2.kicad_sch]
2026-04-02 Minor Ground Revision FL V4
    [Fault Latch 2.kicad_pcb]
2026-04-02 Final RTO Fault Latch V4
    [Fault Latch 2.kicad_pcb]
2026-04-05 IR holder board
    [IRresistable.kicad_pcb, IRresistable.kicad_sch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]
2026-04-06 FINAL RTO FL V4
    Added tables for I/O and fixed some traces
    [Fault Latch 2-B_Cu.gbl, Fault Latch 2-B_Mask.gbs, Fault Latch 2-B_Paste.gbp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]
2026-04-23 charging holes
    added M4 holes to charging
    [ChargingPCB26.kicad_pcb]
2026-04-24 Added modal for Prechg, FL
    Look in PCBMOdal26 file and open respective workbench files for precharge and FL, figure it out
    [BPSD-2025.step, ChargingPCB26.step, Discharge26.step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]
2026-04-29 Fixed Discharge + Added RML Quick files
    [Discharge26.kicad_pcb, Discharge26.kicad_sch, Discharge_designators.csv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]
2026-05-16 Fixed up the Git a bit + added RML Quick and RML LED Driver
    [B3FS_1000.step, Fault Latch 2- THT.kicad_sch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]
2026-05-16 Added up to date BSPD back to git bc yianni is a bum
    [1053131102.stp, 1053131104.stp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]
2026-06-02 Added Remade RML and Safety Circuit
    [0430450801.stp, 1053131202.stp, 1053141312.stp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]
2026-06-02 Fixed Small Comparator issue on RML Switiching
    [RML HVI.kicad_pcb, RML HVI.kicad_sch]
2026-06-15 precharge code
    removed delay on precharge teensy
2026-07-15 Sorted the Git into before 27 and 27 designs
    Also started on a new fault latch design
    [0430450801.stp, 0447640401.stp, 1053131102.stp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]
2026-07-15 Revert "Sorted the Git into before 27 and 27 designs"
    This reverts commit 48352413fd02368e343e4655dbcb4272930f2309.
    [0430450801.stp, 0447640401.stp, 1053131102.stp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]
